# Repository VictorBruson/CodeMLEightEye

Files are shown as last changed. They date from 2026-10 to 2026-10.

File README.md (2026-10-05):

# EightEye

**Turn recycled lenses into custom 3D-printed glasses.**

EightEye is a mobile web app that takes a photo of a recycled eyeglass lens, measures its shape to the millimetre, and generates a 3D-printable frame that fits it, even when the left and right lenses have different shapes. It is our answer to the **OptiFrame** challenge from Santé Numérique Sans Frontières (SN-SF), built for the CodeML hackathon.

- Devpost: https://devpost.com/software/eighteye-s5tnwm
- Demo video: https://www.youtube.com/watch?v=NqhWV81mBPg

## Why

In medical deserts and humanitarian settings, opticians are rare or out of reach, yet usable corrective lenses exist: donations, end-of-line stock, lenses taken from used glasses. The expensive part of a pair of glasses is the frame and the fitting. A recycled lens also has its own shape, and one prescription can pair two different shapes, one per eye, so a standard frame does not fit.

Opticians measure a lens outline with a costly tracer. We replace that machine with a phone, and the frame with a few dollars of 3D-printer filament.

## What it does

1. **Capture.** Photograph each lens, left and right, on a plain surface next to a standard bank card. The card (85.6 x 53.98 mm) gives the app a known size.
2. **Measure.** The app straightens the photo into a top-down view, finds the lens outline, and shows its width (A), height (B) and perimeter in millimetres, with an overlay so you can check what it "saw".
3. **Generate.** It builds a 3D frame whose rims follow each lens's exact shape, joined by a bridge (18 mm by default) and with temple tenons that have pin holes.
4. **Preview and export.** You get a rotatable 3D preview, a downloadable **STL** for printing, and a **1:1 SVG** contour sheet to print and lay the real lens on.
5. **Check.** Every frame is validated (watertight mesh, single connected body, printable without excessive supports) and the app warns you if something is off.

No account and no API key are needed.

## How it works

Three layers, built in parallel and joined by a shared JSON contract.

### Vision (OpenCV, NumPy)

- Detects the bank card from colour and edge cues, checks its aspect ratio against a real card, and refines the corners by line fitting.
- Applies a perspective transform to a top-down view at a fixed pixels-per-millimetre scale.
- Segments the lens from **edge gradients rather than brightness**, since a transparent lens shows in its edges, not its surface. It tries several gradient thresholds, closes and fills the rim, filters by area, aspect ratio and solidity, then refines the rim with 720 rays and a dynamic-programming edge search.
- A Fourier-smoothed contour gives a robust A and B using the ISO 8624 "boxing" convention.

### Geometry (Shapely, trimesh, manifold3d)

- **Lens cleanup.** The outline is repaired, resampled to evenly spaced points, smoothed with an FFT low-pass, and recentred on its boxing centre. The smoothing is tested to move A and B by less than 0.1 mm, including on sharp-cornered shapes.
- **Layout.** Each lens is placed by its eye (the right-eye lens on the viewer's left, nasal side toward the centre), with the two lens boxes the chosen bridge width apart.
- **Frame.** Each rim is the lens grown by a clearance plus a wall. The bridge and the temple tenons are added, everything is extruded, and the lens openings are cut with manifold boolean operations. The openings have a ledge, a pocket and a stepped 45-degree entry lip so each lens clicks in and stays put, and the frame prints flat on its back face without supports.
- **Validation.** Each mesh is checked for watertightness, a single connected body, and overhang, with plain-language warnings.

### API (FastAPI)

- One endpoint measures two photos and returns the contour contract and overlays.
- A second turns the contract into a base64 STL, a 1:1 SVG and a validation report.
- Bad input returns a clear, non-technical message in one consistent error format.

### Frontend (React, TypeScript, Vite, three.js)

A mobile-first flow with in-app camera capture and a file-picker fallback, result overlays, an interactive STL viewer (React Three Fiber) and download buttons.

## Data and AI

The current segmentation is **classical computer vision** (gradients, contours, ray search, Fourier smoothing). We do not yet use a trained segmentation model or an external dataset, so there are no model or dataset licences to cite. Training or fine-tuning a segmentation model on a purpose-built dataset (real, synthetic and augmented photos) for harder cases is our main next step.

## Built with

Python, FastAPI, uvicorn, pydantic, NumPy, OpenCV, Pillow, Shapely, trimesh, manifold3d, mapbox-earcut, networkx, pytest, React, TypeScript, Vite, three.js, React Three Fiber, drei, the browser camera API (`getUserMedia`), and Cloudflare Tunnel (`cloudflared`) for testing over HTTPS.

## Team

[An-Khiem Le](https://github.com/akybreaky), [Pamela Daniel](https://github.com/bypameladaniel), [Victor Bruson](https://github.com/VictorBruson), [Quinton Shannon](https://github.com/qrs-programmer)

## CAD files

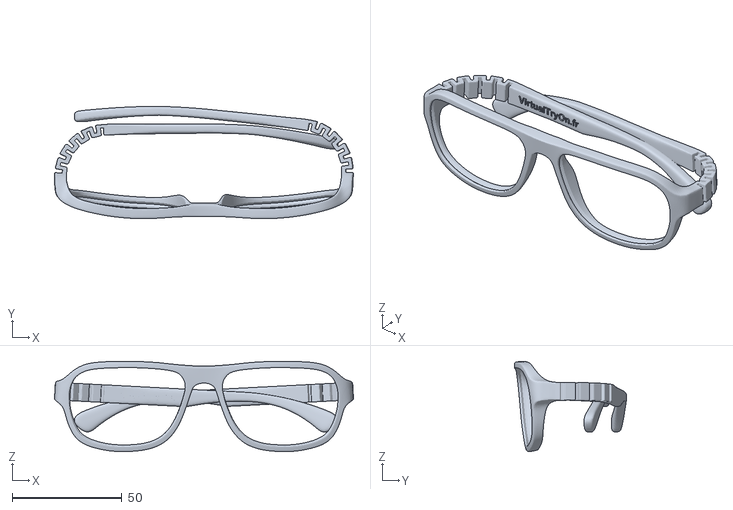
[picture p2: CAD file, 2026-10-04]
frontend/ressources/steve_block.stl
136.0 x 51.1 x 41.0

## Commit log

2026-10-03 feat: add module to clean and smooth lens polygons for 3D rendering
2026-10-03 feat: build simple 3D frame
2026-10-03 feat: add tenons to 3D frame
2026-10-03 Lens outline and masking through Numpy and OpenCV
2026-10-04 camera cloudflared fix
2026-10-04 fix: make camera full screen
2026-10-04 feat: create endpoint for 3D frame generation
2026-10-04 frame viewer
    [steve_block.stl]
2026-10-04 fix: remove camera error
2026-10-04 feat: generate SVG from lens contour
2026-10-04 feature: integrate /frame endpoint to frontend
2026-10-04 fixed backend to start with main.py, modified frame viewer
2026-10-04 trying to integrate FrameApiResponse in frontend
2026-10-04 feat: add groove for lens in 3D frame
